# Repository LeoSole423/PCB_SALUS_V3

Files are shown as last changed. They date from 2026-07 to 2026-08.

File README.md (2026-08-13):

# PCB SALUS V3

PCB de control para el robot Ackermann SALUS. Esta revision se inspira en la
arquitectura de `Hoja-Base`, pero usa un ESP32-S3 y se mantiene como un diseno
independiente.

## Abrir el proyecto

En KiCad 10, abre `PCB_SALUS_v3.kicad_pro`. El esquema raiz contiene tres
hojas jerarquicas activas: `ESP32`, `SENSORES` y `ALIMENTACION`.

La PCB esta sincronizada de forma parcial y aun no tiene placement ni ruteo
final. No debe enviarse a fabricar hasta completar la revision electrica,
placement, ruteo, DRC y pruebas de banco.

## Arquitectura actual

- `U8`: ESP32-S3-WROOM-1-N8R2 como controlador de tiempo real e I/O.
- `U9`: buck AP63203WU-7 que convierte `5V_SYS` a `+3.3V`.
- Dos receptaculos USB-C: `J3` para UART0 mediante CP2102N y `J16` para el USB
  nativo del ESP32-S3.
- BMI088, I2C externo, puente BTS7960, salidas de reles, sensores Hall,
  finales de carrera, acelerador, RF PPM, UART1 y dos headers de servo.
- Entrada manual de 5 V por `J5` y entrada manual de 7 V por `J19`.

## Documentacion

- [Contexto del proyecto](docs/00_CONTEXTO_PROYECTO.md)
- [Estructura del esquematico y librerias](docs/01_ESTRUCTURA_ESQUEMATICO_Y_LIBRERIAS.md)
- [Validacion y pruebas](docs/02_VALIDACION_Y_PRUEBAS.md)
- [Revision BOM y huellas JLCPCB](docs/03_REVISION_BOM_JLCPCB.md)
- [Puente H BTS7960](docs/04_PUENTE_H_BTS7960.md)
- [Mapa de submodulos y pinout](docs/05_MAPA_DE_SUBMODULOS_Y_PINOUT.md)
- [Revision V3](docs/06_REVISION_V3_2026-07-15.md)
- [Generacion CPL auditable KiCad → JLCPCB](docs/07_CPL_AUDITABLE_KICAD_JLCPCB.md)
- [Validacion del filtro PWM del acelerador](docs/08_VALIDACION_FILTRO_ACELERADOR_PWM.md)

## CPL para JLCPCB

Para toda exportación futura de montaje usar exclusivamente
`tools/jlc_cpl.py` y el perfil versionado `config/jlcpcb-cpl.json`. La guía
incluye el flujo reproducible para agentes, auditoría de centroides y
calibración desde el visor de JLCPCB. No editar rotaciones o posiciones
directamente en un CSV.

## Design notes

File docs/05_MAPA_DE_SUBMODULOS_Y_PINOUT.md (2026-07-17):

# Mapa de submodulos y pinout

Fecha de actualizacion: 2026-07-15.

## Alimentacion

`J5` recibe `5V_SYS` desde el step-down externo. `U9` AP63203WU-7, `L2`, C28,
C30/C31 y C22/C23 generan `+3.3V` para la logica. `J19` recibe `+7V` externo
para los servos; no atraviesa el buck de 3.3 V.

## ESP32-S3

U8 es `ESP32-S3-WROOM-1-N8R2`. Las etiquetas activas del esquema relacionan
las interfaces de la siguiente forma.

| Funcion | Red | GPIO / pin U8 |
|---|---|---|
| I2C SDA / SCL | I2C_SDA / I2C_SCL | GPIO7 / GPIO8 |
| SPI MOSI / MISO / reloj | SPI_MOSI / SPI_MISO / SPI_CLOCK | GPIO11 / GPIO13 / GPIO12 |
| BMI088 CS accel / gyro | CS_ACCEL / CS_GIRO | GPIO9 / GPIO10 |
| BMI088 INT accel / gyro | DR_ACCEL / DR_GIRO | GPIO14 / GPIO15 |
| BTS7960 R / L PWM | R_PWM / L_PWM | GPIO4 / GPIO5 |
| Habilitacion BTS7960 | HBRIDGE_EN | GPIO6 |
| Finales de carrera | FC_LEFT / FC_RIGHT | GPIO1 / GPIO2 |
| RF PPM | RF_PPM | GPIO16 |
| Rele latch / OE | RELAY_LATCH / RELAY_OE | GPIO38 / GPIO39 |
| Servos | SERVO1_PWM / SERVO2_PWM | GPIO40 / GPIO41 |
| Acelerador PWM | THROTTLE_PWM | GPIO21 |
| UART0 | U0TX / U0RX | TXD0 / RXD0 |
| UART1 | U1_TX / U1_RX | senales expuestas en J4; validar asignacion final en firmware |
| Arranque / reset | BOOT / RESET | GPIO0 / EN |

## USB y programacion

| Interfaz | Conector | Red | Funcion |
|---|---|---|---|
| UART0 USB | J3 | USB_DP / USB_DM | CP2102N U3, UART0 y autoprogramacion Q3/Q4. |
| USB nativo | J16 | USB2_DP / USB2_DM | D- y D+ nativos del ESP32-S3. |
| Debug manual | J1 | U0TX, U0RX, RESET, BOOT | Programacion y diagnostico alternativo. |
| UART1 | J4 | U1_TX, U1_RX, GND | Interfaz externa de tres pines. |

D2 protege J3 y D5 protege J16. Ambos USB-C son SMD para JLCPCB; todos los
demas conectores son headers THT de soldadura manual.

## Sensores

- `U4` BMI088 usa `IMU_3.3`, SPI compartido y CS separados. SDO1 y SDO2 se
  unen a `SPI_MISO`; la seleccion exclusiva depende de `CS_ACCEL` y `CS_GIRO`.
- `J2` conecta AS5600 y `J12/J13` exponen I2C externo: +3.3V, GND, SDA, SCL.
- `J7/J8` son finales de carrera en `FC_LEFT/FC_RIGHT`.
- `J14` recibe `HALL_A`, `HALL_B`, `HALL_C` y GND.
- `J11` corresponde al acelerador y `J15` al receptor RF PPM.

## Actuadores

- `J6` conecta el BTS7960 con GND, +5V, dos EN y `L_PWM/R_PWM`; los pines IS
  siguen sin conectar. Ver [Puente H BTS7960](04_PUENTE_H_BTS7960.md).
- `U5` SN74HC595 y `U6` ULN2003A forman el expansor de salidas para J9/J10.
- `J17` es SERVO2 y `J18` es SERVO1: pin de +7V, GND y PWM segun el orden
  dibujado. Confirmar orden de conector y corriente de servo antes del PCB.

## Pendientes de interfaz

- R2/R3 y el acondicionamiento de finales de carrera requieren valor.
- Nombrar las cargas finales de J9/J10 y la salida de acelerador.
- Definir el modulo GPS RTK, su conector, protocolo y alimentacion.
- Unificar las etiquetas HBRIDGE_EN/HB_EN en la proxima correccion electrica.

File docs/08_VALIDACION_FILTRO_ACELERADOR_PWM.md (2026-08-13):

# Validacion del filtro PWM del acelerador

Fecha de validacion: 2026-08-13.

## Veredicto

Se adopta `R17 = 47 kOhm`, `C20 = 100 nF`, encapsulados 0603 y PWM de
`20 kHz`. La constante de tiempo se conserva en 4.7 ms y no cambian la
huella, el ruteo ni la colocacion.

La cadena real es `GPIO21 / THROTTLE_PWM -> R17 -> C20 a GND -> U7A` (seguidor)
`-> R18 -> J11 / THROTTLE_OUT`, con `R19` como pull-down de salida. `R35 =
100 kOhm` esta directamente en el GPIO: fija nivel bajo durante arranque, pero
no forma un divisor mientras el GPIO conduce activamente.

| Parametro nominal | Resultado |
|---|---:|
| Constante de tiempo R17-C20 | 4.70 ms |
| Corte de -3 dB | 33.86 Hz |
| Respuesta 10-90 % | 10.33 ms |
| Escala de salida R18/R19 | 0.993028 |
| Salida a 100 % PWM, carga alta Z | 3.27699 V |

El LM358 se alimenta con 5 V. La entrada de 0-3.3 V queda dentro de su rango
de modo comun especificado hasta aproximadamente `V+ - 1.5 V`; la carga de
R18/R19 a fondo de escala es solo unos 70 uA. Esta conclusion depende de que
J11 conecte una entrada de alta impedancia, como se asumio para esta revision.

## Simulacion SPICE

Los bancos reproducibles estan en
[`spice/validar_filtro_acelerador.cir`](../spice/validar_filtro_acelerador.cir)
y [`spice/validar_escalon_acelerador.cir`](../spice/validar_escalon_acelerador.cir).
Modelan GPIO de baja impedancia, R35, el RC, un seguidor ideal U7A y la salida
R18/R19. La idealizacion del seguidor es valida para el filtro de 33.86 Hz;
la ganancia-ancho de banda nominal del LM358 es muy superior a esa frecuencia.

Resultados transitorios con ngspice:

| PWM | Ciclo util | Salida media | Rizado pico a pico |
|---:|---:|---:|---:|
| 20 kHz | 0 % | 0 V | 0 V |
| 20 kHz | 10 % | 0.32774 V | 3.18 mV |
| 20 kHz | 50 % | 1.63852 V | 8.77 mV |
| 20 kHz | 90 % | 2.94934 V | 3.22 mV |
| 20 kHz | 100 % | 3.27699 V | 0 V |

El escalon de 0 a 100 % simulado mide 10.327 ms entre 10 y 90 %. Por lo tanto,
el caso de peor rizado nominal a 20 kHz es 8.77 mVpp (0.27 % de 3.3 V): cumple
el limite de 15 mVpp y la respuesta esperada para un mando mecanico.

La comparacion de frecuencia se calculo con la respuesta periodica exacta del
RC, validada por SPICE en 10, 20, 40 y 80 kHz; el maximo ocurre a 50 % de ciclo
util. Se expresa en J11, despues del divisor R18/R19.

| Frecuencia PWM | Rizado maximo a 50 % |
|---:|---:|
| 10 kHz | 17.43 mVpp |
| 20 kHz | 8.72 mVpp |
| 40 kHz | 4.36 mVpp |
| 80 kHz | 2.18 mVpp |
| 100 kHz | 1.74 mVpp |

Subir el PWM disminuye el rizado, pero no resuelve un problema presente. A
cambio, reduce la resolucion de duty util del temporizador LEDC de la
ESP32-S3: con un reloj de 80 MHz, la condicion `frecuencia x 2^bits <= 80 MHz`
permite como maximo 11 bits a 20 kHz, 10 bits a 40 kHz y 9 bits a 80 kHz. Se
mantiene 20 kHz.

## Tolerancias y margen

Para un caso conservador se uso R17 a -1 %, C20 a -10 % y una reduccion
adicional de 15 % de capacidad por sesgo DC: `R = 46.53 kOhm`, `C = 76.5 nF`.
SPICE entrega 11.52 mVpp a 20 kHz y 50 %, aun inferior a 15 mVpp. El tiempo
10-90 % queda aproximadamente entre 7.8 y 11.4 ms en los extremos pasivos;
mas rapido que el nominal no perjudica la respuesta del acelerador.

La corriente de polarizacion del LM358 es tipicamente 20 nA. Incluso usando
250 nA como cota conservadora, R17 puede introducir hasta 11.75 mV de error
DC; es aceptable para una escala de 3.3 V, pero reduce el margen frente a la
solucion original de 4.7 kOhm.
La salida a 100 % se reduce por R18/R19, no por el filtro; una carga externa
de baja impedancia reduciria esa tension y requeriria redisenar la etapa de
salida. No conectar J11 a una carga baja sin revisar ese supuesto.

## Coste y tamano

`R17 = 47 kOhm` y `C20 = 100 nF` conserva exactamente `RC = 4.7 ms`. Ambos
son 0603 y no reducen area de PCB. Se eligieron C25819 para R17 y C14663 para
C20: son piezas Basic de JLCPCB, al igual que C14663 para los otros once
capacitores de 100 nF.

La mayor impedancia aumenta la susceptibilidad a ruido y el error por corriente
de polarizacion indicado arriba. Se acepta para la entrada de alta impedancia
de J11 a cambio de eliminar C1590 y C108463, dos referencias Extended. El
ahorro estimado para cinco PCBA es USD 5.60; confirmar precio y disponibilidad
antes de pagar en [LCSC para C14663](https://www.lcsc.com/product-detail/Multilayer-Ceramic-Capacitors-MLCC-SMD-SMT_YAGEO-CC0603KRX7R9BB104_C14663.html).

## Criterio de banco antes de integrar

1. Con J11 sin carga, medir a 0, 10, 50, 90 y 100 % de PWM con sonda x10 y
   masa corta; esperar los valores medios de la tabla y menos de 15 mVpp.
2. Confirmar que el controlador conectado a J11 acepta 0-3.3 V y presenta alta
   impedancia en toda la escala.
3. Arrancar y resetear la ESP32 verificando que R35 mantiene la salida proxima
   a 0 V hasta que el firmware configure GPIO21.

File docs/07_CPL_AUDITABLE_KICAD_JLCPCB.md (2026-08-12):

# CPL auditable: KiCad → JLCPCB

`tools/jlc_cpl.py` es el único procedimiento admitido para crear un CPL nuevo.
No se editan coordenadas ni rotaciones directamente en un CSV: toda excepción
queda en `config/jlcpcb-cpl.json`, con motivo y fuente.

## Contrato JLCPCB

El archivo final contiene exactamente `Designator,Mid X,Mid Y,Layer,Rotation`.
Las coordenadas llevan `mm`, la capa es `Top` o `Bottom` y la rotación está en
`[0,360)`. JLCPCB interpreta `Mid X/Mid Y` como el centroide de colocación y
la rotación positiva en sentido antihorario. La herramienta parte del origen
auxiliar de KiCad; el perfil especifica el signo de los ejes, por lo que nunca
debe invertirse Y en una hoja de cálculo.

## Centros y reglas

KiCad puede tener tres centros diferentes:

- `anchor`: origen de la huella, que es el origen del exportador de KiCad.
- `pad_center`: centro de la envolvente de pads; útil para hallar anclas
  excéntricas, pero no es automáticamente el centro de montaje.
- `body_center`: estimación a partir de geometría de huella/courtyard.

Si cualquiera difiere más de 0,20 mm, el informe exige una regla explícita o
marca el componente `needs_review`. Esto sucede, por ejemplo, en U1, U8 y
J16. La imagen 3D de JLCPCB no es por sí sola una prueba de que el centro
matemático sea erróneo.

Las reglas tienen precedencia: referencia, LCSC, huella exacta, regex de
familia y base KiCad. Cada una admite `rotation_offset_deg`,
`position_offset_local_mm`, `origin`, `reason`, `source` y `confirmed_on`.
El offset se rota junto con la huella. Dos reglas coincidentes del mismo nivel
son un error: un agente debe resolverlas, no elegir arbitrariamente.

## Flujo para agentes y CI

```bash
/usr/bin/python3 tools/jlc_cpl.py generate PCB_SALUS_v3.kicad_pcb \
  --config config/jlcpcb-cpl.json \
  --bom fabricacion/JLCPCB_2026-08-12_SALUS_v3/PCB_SALUS_v3-JLC-BOM.csv \
  --output /tmp/salus-cpl.csv --raw-output /tmp/salus-cpl-raw.csv \
  --report /tmp/cpl-audit.json --review-output /tmp/cpl-review.csv \
  --overlay /tmp/cpl-overlay.svg

/usr/bin/python3 tools/jlc_cpl.py validate PCB_SALUS_v3.kicad_pcb \
  --config config/jlcpcb-cpl.json --bom fabricacion/JLCPCB_2026-08-12_SALUS_v3/PCB_SALUS_v3-JLC-BOM.csv \
  --cpl /tmp/salus-cpl.csv --report /tmp/cpl-validation.json

/usr/bin/python3 tools/jlc_cpl.py diff /tmp/salus-cpl-raw.csv /tmp/salus-cpl.csv \
  --output /tmp/cpl-diff.json
```

`generate` retorna 0 solo si la lista es completa y ningún elemento exige
revisión; 2 representa un resultado generado pero no liberable; 3 representa
un error de entrada/configuración. Sus informes JSON son la fuente de verdad
para otro agente.

## Calibración desde el visor JLCPCB

Después de cargar Gerbers, BOM y CPL, registrar solo observaciones inequívocas:

```json
{
  "observations": [{
    "reference": "U2",
    "origin": "anchor",
    "rotation_offset_deg": 90,
    "position_offset_local_mm": [0, 0],
    "reason": "Pin 1 del componente JLC coincide con pin 1 de la huella",
    "source": "JLCPCB viewer, captura enlazada",
    "confirmed_on": "2026-08-12"
  }]
}
```

Proponer la modificación sin tocar nada:

```bash
/usr/bin/python3 tools/jlc_cpl.py calibrate config/jlcpcb-cpl.json \
  --observations observaciones.json --output /tmp/reglas-propuestas.json --dry-run
```

Tras revisión humana, ejecutar de nuevo con `--apply`, regenerar, comparar y
volver a inspeccionar. Solo entonces se actualiza el paquete de fabricación y
su checksum. Gerbers y BOM no cambian por una corrección exclusiva del CPL.

La aceptación exige cuerpos sobre pads y pin 1/polaridad correctos para todos
los componentes asimétricos, no solo una previsualización global aparentemente
alineada.

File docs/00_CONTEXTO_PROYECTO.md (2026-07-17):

# Contexto de PCB SALUS V3

## Objetivo

SALUS V3 es la placa de control de bajo nivel para un robot Ackermann. La
Jetson Orin Nano conserva las tareas de alto nivel y el ESP32-S3 se ocupa de
FreeRTOS, adquisicion de sensores, PID, entradas, salidas y comunicaciones de
campo. La placa no controla directamente la potencia de traccion.

## Arquitectura confirmada

```text
Jetson Orin Nano <--> USB / UART segun interfaz <--> ESP32-S3
                                                    |-- sensores e IMU
                                                    |-- actuadores de logica
                                                    `-- headers de servo

Step-down externo 5 V --> J5 --> 5V_SYS --> AP63203WU-7 --> +3.3V
Step-down externo 7 V --> J19 --> +7V --> J17/J18 (servos)
```

- `U8` es `ESP32-S3-WROOM-1-N8R2`, con 8 MB de flash y 2 MB de PSRAM.
- `U9` es `AP63203WU-7`, buck fijo de 3.3 V desde el riel `5V_SYS`.
- `J3` ofrece USB-C a UART0 mediante `U3` CP2102N y conserva la
  autoprogramacion por `Q3/Q4`.
- `J16` ofrece USB-C nativo del ESP32-S3 mediante `USB2_DP` y `USB2_DM`.
- `J17` y `J18` son headers de tres pines para servo; `J19` recibe el riel de
  7 V externo.

## Ensamblaje JLCPCB

La placa requiere PCBA Standard por el modulo ESP32-S3 y la IMU BMI088. Los
componentes SMD se montaran en la cara superior. Todos los headers son THT y
se compran/sueldan manualmente: permanecen en la PCB para fabricar sus agujeros
metalizados, pero se excluyen de la BOM y CPL de ensamblaje.

Las existencias y precios de JLCPCB son una fotografia de la fecha de revision;
deben comprobarse nuevamente antes del pedido.

## Limites actuales

- `J5` recibe 5 V ya regulados. El esquema activo no implementa corte por
  sobretension, fusible ni TVS de entrada frente a una falla aguas arriba.
- `J19` recibe 7 V ya regulados para los servos. La capacidad de corriente del
  header y del cableado debe confirmarse frente a los picos de servo antes del
  layout final.
- La proteccion de la Jetson y sus 19 V no pertenece a esta placa.
- GPS RTK de doble antena sigue sin modulo, conector, protocolo ni pinout
  definido.
- `R2` y `R3` aun tienen valor `R`; no se pueden comprar ni montar hasta que
  se defina el acondicionamiento de los finales de carrera.

## Principios de diseno

- Mantener potencia de traccion, 7 V de servos y logica de 3.3 V separados en
  placement, retorno de masa y ruteo.
- Respetar el keep-out de antena del ESP32-S3 en todas las capas de cobre.
- Situar TVS junto a cada USB-C y desacoples junto a sus pines de alimentacion.
- Resolver ERC, DRC, fiduciales, puntos de prueba y conexion de entradas
  externas antes de fabricar.

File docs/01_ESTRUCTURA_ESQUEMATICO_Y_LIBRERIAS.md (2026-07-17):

# Estructura del esquematico y librerias

## Hojas activas

| Hoja | Responsabilidad |
|---|---|
| `ESP32.kicad_sch` | ESP32-S3, USB-C UART0, USB-C nativo, CP2102N y autoprogramacion. |
| `SENSORES.kicad_sch` | IMU, sensores, BTS7960, reles, servo y conectores de campo. |
| `ALIMENTACION.kicad_sch` | Entrada 5 V, buck AP63203WU-7, entrada 7 V y rieles globales. |

El archivo raiz `PCB_SALUS_v3.kicad_sch` solo organiza las hojas. Las senales
de aplicacion se intercambian por etiquetas globales y los rieles usan simbolos
de potencia. Antes de crear una hoja nueva, definir su alimentacion, interfaz
y conector asociado.

## Bibliotecas del proyecto

`sym-lib-table` y `fp-lib-table` hacen que el proyecto use bibliotecas locales
de `Libs/` ademas de las bibliotecas estandar de KiCad.

```text
PCB_SALUS_v3/
  Libs/
    Symb/Simbolos.kicad_sym
    Footprints/Footprints.pretty/
    3D/
```

Usar una huella local solo cuando la huella estandar no coincida con el dibujo
mecanico del MPN. Para cada pieza SMD, verificar simbolo, pinout, pad 1,
encapsulado, MPN, fabricante y `LCSC PN`. Los headers THT llevan una huella
estandar de KiCad pero se anotan como `Compra manual` y se excluyen de PCBA.

## Actualizar la PCB

Despues de guardar cambios en las hojas, abrir el editor PCB y usar
`Herramientas -> Actualizar PCB desde el esquematico` (F8). Revisar la lista de
cambios antes de aceptar; no mover ni borrar componentes que ya hayan sido
colocados sin revisar el impacto. Esta accion no reemplaza el DRC.

## Modelos 3D

Los modelos de `Libs/3D/` son utiles para comprobar interferencias mecanicas,
pero no validan pinout, pad mapping ni compatibilidad con JLCPCB.

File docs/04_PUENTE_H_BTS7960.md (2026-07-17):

# Puente H BTS7960 para direccion

## Alcance

`J6` conecta la PCB SALUS V2 con un modulo externo IBT-2 basado en dos
BTS7960. El modulo conmuta la potencia del motor delantero; la PCB solo entrega
logica de 5 V y senales de control. La corriente del motor no debe circular por
la PCB SALUS ni por este conector de senales.

## Conexion actual de J6

| Pin J6 | Red SALUS | Funcion esperada del modulo |
|---|---|---|
| 1 | GND | Masa de logica. |
| 2 | +5V | Alimentacion de la logica del modulo. |
| 3 | Sin etiqueta | R_IS, sensado de corriente de un sentido. |
| 4 | Sin etiqueta | L_IS, sensado de corriente del otro sentido. |
| 5 | HBRIDGE_EN | R_EN. |
| 6 | HBRIDGE_EN | L_EN. |
| 7 | L_PWM | Entrada PWM de un sentido. |
| 8 | R_PWM | Entrada PWM del sentido opuesto. |

La conexion de los dos `EN` a `HBRIDGE_EN` es valida: en bajo deshabilita el
puente y en alto permite operar ambos sentidos. El firmware debe garantizar que
solo uno entre `L_PWM` y `R_PWM` este activo a la vez. Ambos en bajo dejan el
motor sin mando; para un paro seguro, poner `HBRIDGE_EN` en bajo.

Los modulos IBT-2 no tienen una numeracion fisica universal. Antes de conectar
la primera vez, comparar la serigrafia del modulo real y el pin 1 del cable con
esta tabla. No usar solo fotos de vendedores como referencia de pinout.

## Recomendaciones de hardware

1. Agregar un pull-down externo de 10 kOhm desde `HBRIDGE_EN` a GND. Deja el
   puente deshabilitado mientras el ESP32 arranca, se resetea o queda sin
   alimentacion.
2. Agregar pull-downs de 10 kOhm desde `L_PWM` y `R_PWM` a GND. Evitan pulsos
   de mando durante el arranque. No usar pull-ups a 5 V en estas redes: pueden
   retroalimentar un ESP32 apagado.
3. Si el cable entre PCB y modulo no es muy corto, agregar resistores serie de
   100 a 330 Ohm en `HBRIDGE_EN`, `L_PWM` y `R_PWM`, ubicados en la PCB SALUS.
   Reducen ringing, EMI y corriente de ESD hacia el ESP32.
4. Considerar un TVS de baja capacitancia para las tres senales y GND si el
   cable sale de una caja protegida o supera aproximadamente 20 cm. No es
   obligatorio para un cable interno corto, pero mejora robustez en un robot.
5. El modulo debe tener cerca de sus bornes `B+` y `B-` un capacitor ceramico de
   100 nF y un electrolitico low-ESR de al menos 470 uF, ambos con tension
   nominal superior al riel del motor. La foto muestra un electrolitico en el
   modulo; comprobar valor, tension y distancia real a los bornes. Estos
   capacitores no reemplazan la proteccion ni el filtrado del riel de motor.
6. Unir GND de logica y el negativo de potencia del modulo en el sistema, pero
   llevar el retorno de corriente de motor directamente a la distribucion de
   potencia. No usar la masa de J6 ni la PCB SALUS como retorno de motor.

El BTS7960 admite entradas logicas compatibles con 3.3 V en aplicaciones
tipicas. Aun asi, se debe probar con el modulo real y limitar la prueba inicial
con fuente de laboratorio: los modulos clon pueden variar en sus redes de
entrada.

## Uso de R_IS y L_IS

Cada BTS7960 tiene un pin `IS`: es una fuente de corriente proporcional a la
corriente del lado alto activo y tambien comunica fallas. No es una salida
digital. En el IC original, la relacion nominal es `I_motor / I_IS = 8500`; un
resistor externo de 1 kOhm a GND produciria aproximadamente
`V_IS = I_motor / 8.5 A` en operacion normal. Durante una falla, la salida
indica el estado mediante una corriente limitada.

En modulos IBT-2 el resistor de conversion puede estar ya instalado y su valor
no es consistente entre clones. Por eso, antes de llevar `IS` a un ADC:

1. Con el modulo apagado, medir resistencia entre cada `R_IS`/`L_IS` y GND.
2. Con fuente limitada y motor sin carga, medir la tension `IS` para una
   corriente conocida.
3. Confirmar que la tension maxima, incluidos transitorios, nunca supera 3.3 V.
4. Solo entonces conectar a un ADC1 del ESP32, preferentemente GPIO36
   (`SENSOR_VP`) y GPIO39 (`SENSOR_VN`), que no compiten con Wi-Fi.

Si se usan los dos canales, proponer en la proxima iteracion: etiqueta
`HBRIDGE_R_IS` y `HBRIDGE_L_IS`, resistor serie de 4.7 kOhm a 10 kOhm hacia el
ADC, capacitor de 10 nF a GND en el lado del ADC y clamp a 3.3 V validado para
la corriente de falla. No conectar `IS` directamente al ESP32 hasta medir el
modulo real, porque un nivel de 5 V puede danar su ADC.

La medicion solo representa el semicircuito que esta conduciendo. Debe leerse
el canal asociado al sentido ordenado y calibrarse en software; no sustituye un
sensor de corriente de precision ni una proteccion primaria de sobrecorriente.

## Estado de revision

- `J6` usa `PinHeader_2x04_P2.54mm_Vertical`. Es un header THT vertical de
  montaje manual: JLCPCB debe fabricar los agujeros y pads, pero no montarlo.
  Debe excluirse de la BOM y CPL de ensamblaje JLCPCB.
- Los pines 3 y 4 quedaron como redes sin etiqueta. Si no se usaran ahora,
  colocar marcadores `No connect`; si se reservaran, etiquetarlos como
  `HBRIDGE_R_IS` y `HBRIDGE_L_IS`.
- La relacion completa con la ESP32 y el resto de los conectores esta en el
  [mapa de submodulos y pinout](05_MAPA_DE_SUBMODULOS_Y_PINOUT.md).

## Fuente tecnica

- [Datasheet oficial BTS7960 de Infineon](https://www.infineon.com/assets/row/public/documents/10/57/infineon-bts7960-ds-en.pdf): funcion de `IS`, relacion nominal de corriente y diagnostico.

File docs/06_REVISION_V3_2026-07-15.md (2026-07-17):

# Revision V3 - 2026-07-15

## Cambios aplicados

- Se incorporo `ALIMENTACION.kicad_sch` a la jerarquia raiz.
- U8 quedo fijado como `ESP32-S3-WROOM-1-N8R2` / `C2913204`.
- U9 quedo fijado como `AP63203WU-7` / `C780769`; L2 usa
  `FXL0530-4R7-M` / `C177246` y su huella dedicada de KiCad.
- C28 recibio huella y pieza de 10 uF. C30/C31 pasaron a una pieza real de
  22 uF (`C45783`) en lugar del MPN previo de 10 uF.
- Se completaron huellas 0603 y MPN/LCSC de los pasivos con valor definido.
- J19 recibio huella THT 1x02; los headers se anotaron como compra manual.

## Hallazgos sin corregir electricamente

| Prioridad | Hallazgo | Accion futura |
|---|---|---|
| Alta | No hay proteccion ante sobrevoltaje, polaridad inversa ni corto en J5. | Definir responsabilidad entre step-down externo y placa. |
| Alta | J19/J17/J18 usan header 2.54 mm para 7 V de servo; falta validar corriente, cable y ancho de pista. | Seleccionar interconexion acorde al pico real y rutear potencia. |
| Alta | PCB sin Edge.Cuts, con 210 conexiones sin rutear, 29 componentes del esquema ausentes y 8 obsoletos. | Ejecutar F8 en PCB Editor, dibujar contorno y realizar placement/ruteo. |
| Alta | DRC actual: 137 violaciones; predominan contorno inexistente, drills de 0.20 mm fuera de la regla actual y serigrafia sobre pads. | Configurar reglas de fabricacion y repetir DRC despues de layout. |
| Media | R2/R3 no tienen valor electrico. | Definir filtro/pull-up de finales de carrera y seleccionar pieza. |
| Media | ERC: HBRIDGE_EN y HB_EN comparten red. | Unificar nombre cuando se haga la revision funcional. |
| Media | SW1/SW2 generan cuatro avisos ERC por sus tipos de pin; la cobertura ESD USB aun requiere revision de layout. | Corregir tipos de simbolo y revisar USB antes de fabricar. |
| Media | BMI088 INT2 no se usa; MISO compartido esta excluido de ERC intencionalmente. | Confirmar configuracion y firmware durante pruebas. |

## Verificacion de huellas

- ESP32-S3: simbolo y huella `RF_Module:ESP32-S3-WROOM-1` corresponden a la
  variante WROOM-1 con antena integrada; el keep-out se valida en layout.
- AP63203WU-7: huella TSOT-23-6 y pinout del simbolo KiCad se revisaron contra
  la documentacion de Diodes Incorporated.
- L2: la huella `L_Changjiang_FXL0530` corresponde al MPN seleccionado.
- CP2102N, BMI088, USB-C, SP0503BAHTG, SS8050 y los SOIC existentes conservan
  huellas compatibles con sus encapsulados registrados. La confirmacion final
  de pad 1 y rotacion se hara durante placement/CPL.

## Cobertura de revision

Se exportaron BOM y netlist desde la raiz y se ejecuto ERC. KiCad CLI no ofrece
una accion para actualizar PCB desde el esquematico y los binarios graficos de
esta instalacion no inician por una incompatibilidad de `libpthread` del snap;
la sincronizacion debe hacerse desde PCB Editor con F8. No se realizaron cambios
de topologia, valores, simulaciones SPICE, placement ni ruteo.

## Datasheets locales

Se creo `datasheets/` con PDFs de AP63203WU-7, ESP32-S3-WROOM-1-N8R2, BMI088,
CP2102N, SP0503BAHTG, SS14, SS8050, SN74HC595DR, ULN2003BDR, LM358DR y SW1/SW2.
El sincronizador no encontro PDF para pasivos, headers manuales, ferrita, L2 y
el USB-C; esto es una brecha documental, no una sustitucion de las propiedades
MPN/LCSC ya asignadas.

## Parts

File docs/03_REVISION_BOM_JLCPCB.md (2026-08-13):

# Revision de BOM y huellas para JLCPCB

Fecha de revision: 2026-07-15.

## Alcance

Se revisaron `ESP32.kicad_sch`, `SENSORES.kicad_sch` y
`ALIMENTACION.kicad_sch`. Todos los SMD con valor definido tienen huella, MPN,
fabricante y `LCSC PN`. La excepcion es `R2/R3`: su valor sigue siendo `R`, por
lo cual quedan sin pieza de compra y no se deben montar.

Los stocks son una fotografia del 2026-07-15. Confirmar disponibilidad, precio,
Basic/Extended y elegibilidad Standard PCBA al preparar el pedido final.

El pedido debe configurarse como `Standard PCBA`, cara superior. U4 (BMI088)
y U8 (ESP32-S3-WROOM-1-N8R2) requieren esta modalidad de ensamblaje; Economic
PCBA no es una opcion valida para esta placa.

## Piezas criticas

| Referencias | MPN / LCSC PN | Huella | Categoria JLC | Stock observado | Decision |
|---|---|---|---|---:|---|
| U8 | ESP32-S3-WROOM-1-N8R2 / C2913204 | RF_Module:ESP32-S3-WROOM-1 | Extended, Standard | 17,776 | Keep-out de antena obligatorio. |
| U9 | AP63203WU-7 / C780769 | TSOT-23-6 | Extended | 615 | Buck fijo de 3.3 V. |
| L2 | FXL0530-4R7-M / C177246 | L_Changjiang_FXL0530 | Extended | 150,986 | 4.7 uH, 4.5 A nominal, 5 A Isat. |
| C28 | CL21A106KPFNNNE / C17024 | 0805 | Extended | 1,868,129 | 10 uF para entrada del buck. |
| C30,C31 | CL21A226MAQNNNE / C45783 | 0805 | Extended | 5,389,915 | 22 uF; reemplaza MPN erroneo de 10 uF. |
| U3 | CP2102N-A02-GQFN24R / C969151 | QFN-24-EP 4x4 | Extended | 5,744 | USB-UART y pad expuesto a GND. |
| U4 | BMI088 / C194919 | Bosch LGA-16 4.5x3 | Extended, Standard | 2,378 | Verificar orientacion, desacople y placement. |
| J3,J16 | GT-USB-7010ASV / C2988369 | USB-C G-Switch | Extended | 32,723 | Un conector UART0 y uno USB nativo. |
| D2,D5 | SP0503BAHTG / C3040626 | SOT-143 | Extended | 28,729 | TVS USB, colocar junto al conector correspondiente. |

## Pasivos consolidados

| Valor | MPN / LCSC PN | Huella | Referencias de esta revision |
|---|---|---|---|
| 100 nF | CC0603KRX7R9BB104 / C14663 | 0603 | C6,C7,C12,C13,C15,C17-C23 |
| 10 uF | CL21A106KPFNNNE / C17024 | 0805 | C5,C8,C28 |
| 22 uF | CL21A226MAQNNNE / C45783 | 0805 | C30,C31 |
| 22 ohm | 0603WAF220JT5E / C23345 | 0603 | R27,R28 |
| 330 ohm | 0603WAF3300T5E / C23138 | 0603 | R11,R18,R20 |
| 4.7 kohm | 0603WAF4701T5E / C23162 | 0603 | R21 |
| 10 kohm | 0603WAF1002T5E / C25804 | 0603 | R1,R8,R9,R12-R16,R22-R24,R34,R36 |
| 47 kohm | 0603WAF4702T5E / C25819 | 0603 | R17,R19 |
| 100 kohm | 0603WAF1003T5E / C25803 | 0603 | R35 |

Los restantes SMD ya conservaban MPN/LCSC validos en el esquema. `R2` y `R3`
mantienen huella 0603 pero no se incluyen como linea de compra hasta definir su
valor electrico.

## Conectores THT manuales

| Referencias | Huella | Uso |
|---|---|---|
| J1,J9,J10 | Header vertical 1x06 P2.54 mm | Debug y cargas. |
| J2,J12,J13,J14 | Header vertical 1x04 P2.54 mm | I2C y sensores. |
| J4,J15,J17,J18 | Header vertical 1x03 P2.54 mm | UART, RF y servos. |
| J5,J7,J8,J11,J19 | Header vertical 1x02 P2.54 mm | Entradas, sensores y 7 V. |
| J6 | Header vertical 2x04 P2.54 mm | BTS7960. |

Todos estan anotados como `Compra manual`; excluirlos de BOM y CPL de JLCPCB.

## Verificacion mecanica pendiente

- Mantener el keep-out de antena de U8 libre de cobre, vias, pistas y metal.
- Colocar D2/D5 antes de las pistas USB y adyacentes a J3/J16.
- Colocar C28, C30/C31 y L2 segun el loop corto VIN-SW-L-COUT de U9.
- Revisar la corriente admisible de J19, J17, J18 y sus pistas antes de usar
  servos con picos cercanos a 5 A.

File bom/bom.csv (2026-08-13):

Reference | Qty | Value | Footprint | MPN | Manufacturer | LCSC | LC_Stock | Chosen_Distributor | Datasheet | Validated | DNP | Notes
C6,C7,C12,C13,C19,C18,C21,C15,C20,C17,C22,C23 | 12 | 100nF | 0603 | CC0603KRX7R9BB104 | Yageo | C14663 |  |  |  |  |  | Huella asignada; consolidar propiedades al cerrar BOM.
C8,C5,C28 | 3 | 10uF | 0805 | CL21A106KPFNNNE | Samsung Electro-Mechanics | C17024
C16,C14 | 2 | 4.7uF | 0805 | CC0805KKX5R6BB475 | YAGEO | C107125
C30 | 1 | 22uF | CP_EIA-3528-21_Kemet-B | T491B226K010AT | KEMET | C117030 |  |  | https://content.kemet.com/datasheets/KEM_T2005_T491.pdf
D1 | 1 | SM712-02HTG | SOT-23 | SM712-02HTG | DOWO | C5449363 |  |  | https://www.littelfuse.com/~/media/electronics/datasheets/tvs_diode_arrays/littelfuse_tvs_diode_array_sm712_datasheet.pdf.pdf
D5 | 1 | SP0503BAHTG | SOT-143 | SP0503BAHTG | Littelfuse | C3040626 |  |  | http://www.littelfuse.com/~/media/files/littelfuse/technical%20resources/documents/data%20sheets/sp05xxba.pdf
D9,D7 | 2 | SS14 | SMA | SS14 | Yangzhou Yangjie Electronic Technology | C2480 |  |  | https://www.vishay.com/docs/88746/ss12.pdf
FB1 | 1 | 600R@100MHz | 0603 | GZ1608D601TF | Sunlord | C1002
J16 | 1 | USB_NATIVO | USB_C_Receptacle_G-Switch_GT-USB-7010ASV | GT-USB-7010ASV | G-Switch | C2988369 |  |  | https://www.usb.org/sites/default/files/documents/usb_type-c.zip
R17,R19 | 2 | 47k | 0603 | 0603WAF4702T5E | UNI-ROYAL | C25819
R20,R11,R18 | 3 | 330 | 0603 | 0603WAF3300T5E | Walsin Technology | C23138 |  |  |  |  |  | Huella asignada.
R21,R2,R3 | 3 | 4.7k | 0603 | 0603WAF4701T5E | Walsin Technology | C23162 |  |  |  |  |  | Huella asignada.
R23,R22,R37,R24,R13,R1,R14,R16,R36,R12,R15,R34 | 12 | 10k | 0603 | 0603WAF1002T5E | UNI-ROYAL(Uniroyal Elec) | C25804 |  |  |  |  |  | Huella asignada.
R25,R26 | 2 | 5.1k | 0603 | 0603WAF5101T5E | UNI-ROYAL(Uniroyal Elec) | C23186
R28,R27 | 2 | 22 | 0603 | 0603WAF220JT5E | Walsin Technology | C23345
R33,R30,R32,R31,R29 | 5 | 1k | 0603 | 0603WAF1001T5E | UNI-ROYAL(Uniroyal Elec) | C21190 |  |  |  |  |  | Huella asignada.
R35 | 1 | 100k | 0603 | 0603WAF1003T5E | Walsin Technology | C25803
SW1,SW2 | 2 |  | Switch-Definitivo | TS-1187A-B-A-B | XKB Connection | C318884 |  |  | http://www.helloxkb.com/uploads/qingchukaiguan/TS-1187A-X-X-X.pdf
U1 | 1 | AMS1117CD-3.3 | TO-252-3_TabPin2 | AMS1117CD-3.3 | Advanced Monolithic Systems | C841796 |  |  | http://www.advanced-monolithic.com/pdf/ds1117.pdf
U2 | 1 | SP3485EN | SOIC-8_3.9x4.9mm_P1.27mm | SP3485EN-L/TR | MaxLinear | C8963 |  |  | http://www.icbase.com/pdf/SPX/SPX00480106.pdf
U4 | 1 | BMI088 | Bosch_LGA-16_4.5x3mm_P0.5mm_LayoutBorder7x1y_ClockwisePinNumbering | BMI088 | Bosch Sensortec | C194919 |  |  | https://www.bosch-sensortec.com/media/boschsensortec/downloads/datasheets/bst-bmi088-ds001.pdf
U5 | 1 | 74HC595 | SOIC-16_3.9x9.9mm_P1.27mm | SN74HC595DR | Texas Instruments | C10092 |  |  | http://www.ti.com/lit/ds/symlink/sn74hc595.pdf |  |  | Montaje SMD JLCPCB.
U6 | 1 | ULN2003A | SOIC-16_3.9x9.9mm_P1.27mm | ULN2003BDR | Texas Instruments | C157485 |  |  | http://www.ti.com/lit/ds/symlink/uln2003a.pdf |  |  | Montaje SMD JLCPCB.
U7 | 1 | LM358 | SOIC-8_3.9x4.9mm_P1.27mm | LM358DR | Texas Instruments | C5423 |  |  | http://www.ti.com/lit/ds/symlink/lm2904-n.pdf |  |  | Montaje SMD JLCPCB.
U8 | 1 | ESP32-S3-WROOM-1 | ESP32-S3-WROOM-1 | ESP32-S3-WROOM-1-N8R2 | Espressif Systems | C2913204 |  |  | https://www.espressif.com/sites/default/files/documentation/esp32-s3-wroom-1_wroom-1u_datasheet_en.pdf |  |  | Modulo Wi-Fi/BLE SMD; mantener libre de cobre y componentes el keep-out de antena indicado por Espressif. JLCPCB: Extended, Standard PCBA.

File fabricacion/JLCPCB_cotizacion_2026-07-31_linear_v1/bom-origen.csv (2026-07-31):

Reference | Value | Footprint | LCSC | MPN | Manufacturer | DNP
C5,C8,C28 | 10uF | Capacitor_SMD:C_0805_2012Metric | C17024 | CL21A106KPFNNNE | Samsung Electro-Mechanics
C6,C12,C13,C15,C17-C19,C21-C23 | 100nF | Capacitor_SMD:C_0603_1608Metric | C1590 | CL10B104KA8NNNC | Samsung Electro-Mechanics
C14,C16 | 4.7uF | Capacitor_SMD:C_0805_2012Metric | C107125 | CC0805KKX5R6BB475 | YAGEO
C20 | 1uF | Capacitor_SMD:C_0603_1608Metric | C108463 | 0603B105K160CT | Walsin Technology
C30 | 22uF | Capacitor_Tantalum_SMD:CP_EIA-3528-21_Kemet-B | C117030 | T491B226K010AT | KEMET
D5 | SP0503BAHTG | Package_TO_SOT_SMD:SOT-143 | C3040626 | SP0503BAHTG | Littelfuse
D7,D9 | SS14 | Diode_SMD:D_SMA | C2480 | SS14 | Yangzhou Yangjie Electronic Technology
FB1 | 600R@100MHz | Inductor_SMD:L_0603_1608Metric_Pad1.05x0.95mm_HandSolder | C1002 | GZ1608D601TF | Sunlord
J1 | Debug_U0 | Connector_PinHeader_2.54mm:PinHeader_1x06_P2.54mm_Vertical |  | Header generico THT 1x06 P2.54 mm | Compra manual
J2 | S_GIRO | Connector_PinHeader_2.54mm:PinHeader_1x04_P2.54mm_Vertical |  | Header manual THT 1x04 P2.54 mm | Compra manual
J4 | Uart1 | Connector_PinHeader_2.54mm:PinHeader_1x03_P2.54mm_Vertical |  | Header generico THT 1x03 P2.54 mm | Compra manual
J5 | 5V_IN | Connector_PinHeader_2.54mm:PinHeader_1x02_P2.54mm_Vertical |  | Header manual THT 1x02 P2.54 mm | Compra manual
J6 | IBT_2 | Connector_PinHeader_2.54mm:PinHeader_2x04_P2.54mm_Vertical |  | Header manual THT 2x04 P2.54 mm | Compra manual
J7 | FC1 | Connector_PinHeader_2.54mm:PinHeader_1x02_P2.54mm_Vertical |  | Header manual THT 1x02 P2.54 mm | Compra manual
J8 | FC2 | Connector_PinHeader_2.54mm:PinHeader_1x02_P2.54mm_Vertical |  | Header manual THT 1x02 P2.54 mm | Compra manual
J9 | RELES_1 | Connector_PinHeader_2.54mm:PinHeader_1x06_P2.54mm_Vertical |  | Header manual THT 1x06 P2.54 mm | Compra manual
J10 | RELES_2 | Connector_PinHeader_2.54mm:PinHeader_1x06_P2.54mm_Vertical |  | Header manual THT 1x06 P2.54 mm | Compra manual
J11 | Throttle | Connector_PinHeader_2.54mm:PinHeader_1x02_P2.54mm_Vertical |  | Header manual THT 1x02 P2.54 mm | Compra manual
J12 | I2C_EXT1 | Connector_PinHeader_2.54mm:PinHeader_1x04_P2.54mm_Vertical |  | Header manual THT 1x04 P2.54 mm | Compra manual
J13 | I2C_EXT2 | Connector_PinHeader_2.54mm:PinHeader_1x04_P2.54mm_Vertical |  | Header manual THT 1x04 P2.54 mm | Compra manual
J14 | S_HALL | Connector_PinHeader_2.54mm:PinHeader_1x04_P2.54mm_Vertical |  | Header manual THT 1x04 P2.54 mm | Compra manual
J15 | RF_PPM | Connector_PinHeader_2.54mm:PinHeader_1x03_P2.54mm_Vertical |  | Header manual THT 1x03 P2.54 mm | Compra manual
J16 | USB_NATIVO | Connector_USB:USB_C_Receptacle_G-Switch_GT-USB-7010ASV | C2988369 | GT-USB-7010ASV | G-Switch
J17 | SERVO2 | Connector_PinHeader_2.54mm:PinHeader_1x03_P2.54mm_Vertical |  | Header manual THT 1x03 P2.54 mm | Compra manual
J18 | SERVO1 | Connector_PinHeader_2.54mm:PinHeader_1x03_P2.54mm_Vertical |  | Header manual THT 1x03 P2.54 mm | Compra manual
J19 | +7V_IN | Connector_PinHeader_2.54mm:PinHeader_1x02_P2.54mm_Vertical |  | Header manual THT 1x02 P2.54 mm | Compra manual
J20 | 3V_IN | Connector_PinHeader_2.54mm:PinHeader_1x02_P2.54mm_Vertical
R1,R12,R15,R16,R24,R34,R36 | 10k | Resistor_SMD:R_0603_1608Metric | C25804 | 0603WAF1002T5E | Walsin Technology
R2,R3,R17,R21 | 4.7k | Resistor_SMD:R_0603_1608Metric | C23162 | 0603WAF4701T5E | Walsin Technology
R11,R18,R20 | 330 | Resistor_SMD:R_0603_1608Metric | C23138 | 0603WAF3300T5E | Walsin Technology
R13,R14,R22,R23 | 10k | Resistor_SMD:R_0603_1608Metric | C25804 | 0603WAF1002T5E | UNI-ROYAL(Uniroyal Elec)
R19 | 47k | Resistor_SMD:R_0603_1608Metric | C25819 | 0603WAF4702T5E | Walsin Technology
R25,R26 | 5.1k | Resistor_SMD:R_0603_1608Metric | C23186 | 0603WAF5101T5E | UNI-ROYAL(Uniroyal Elec)
R27,R28 | 22 | Resistor_SMD:R_0603_1608Metric | C23345 | 0603WAF220JT5E | Walsin Technology
R29-R33 | 1k | Resistor_SMD:R_0603_1608Metric | C21190 | 0603WAF1001T5E | UNI-ROYAL(Uniroyal Elec)
R35 | 100k | Resistor_SMD:R_0603_1608Metric | C25803 | 0603WAF1003T5E | Walsin Technology
SW1,SW2 |  | Footprints:Switch-Definitivo | C318884 | TS-1187A-B-A-B | XKB Connection
U1 | AMS1117CD-3.3 | Package_TO_SOT_SMD:TO-252-3_TabPin2 | C841796 | AMS1117CD-3.3 | Advanced Monolithic Systems
U4 | BMI088 | Package_LGA:Bosch_LGA-16_4.5x3mm_P0.5mm_LayoutBorder7x1y_ClockwisePinNumbering | C194919 | BMI088 | Bosch Sensortec
U5 | 74HC595 | Package_SO:SOIC-16_3.9x9.9mm_P1.27mm | C10092 | SN74HC595DR | Texas Instruments
U6 | ULN2003A | Package_SO:SOIC-16_3.9x9.9mm_P1.27mm | C157485 | ULN2003BDR | Texas Instruments
U7 | LM358 | Package_SO:SOIC-8_3.9x4.9mm_P1.27mm | C5423 | LM358DR | Texas Instruments
U8 | ESP32-S3-WROOM-1 | RF_Module:ESP32-S3-WROOM-1 | C2913204 | ESP32-S3-WROOM-1-N8R2 | Espressif Systems

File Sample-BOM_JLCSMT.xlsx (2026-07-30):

Comment | Designator | Footprint | JLCPCB Part #（optional）
100uF | C1 | CAP-SMD_L3.5-W2.8 | C16133
15K | R5,R6 | R0603 | C22809
DC-005-20A_C136744 | DC1 | DC-IN-TH_DC-005-20A | C136744
Header-Female-2.54_1x8 | P2,P3 | HDR-TH_8P-P2.54-V | C27438
K2-1102DP-C4SW-04 | SW1 | KEY-TH_4P-L6.0-W6.0-P4.50-LS6.5 | C110153
ATMEGA328P-PU | U1 | DIP-28_L34.6-W7.3-P2.54-LS10.2-BL | C33901
670688000 | USB1 | USB-B-TH_67068-8000 | C114097

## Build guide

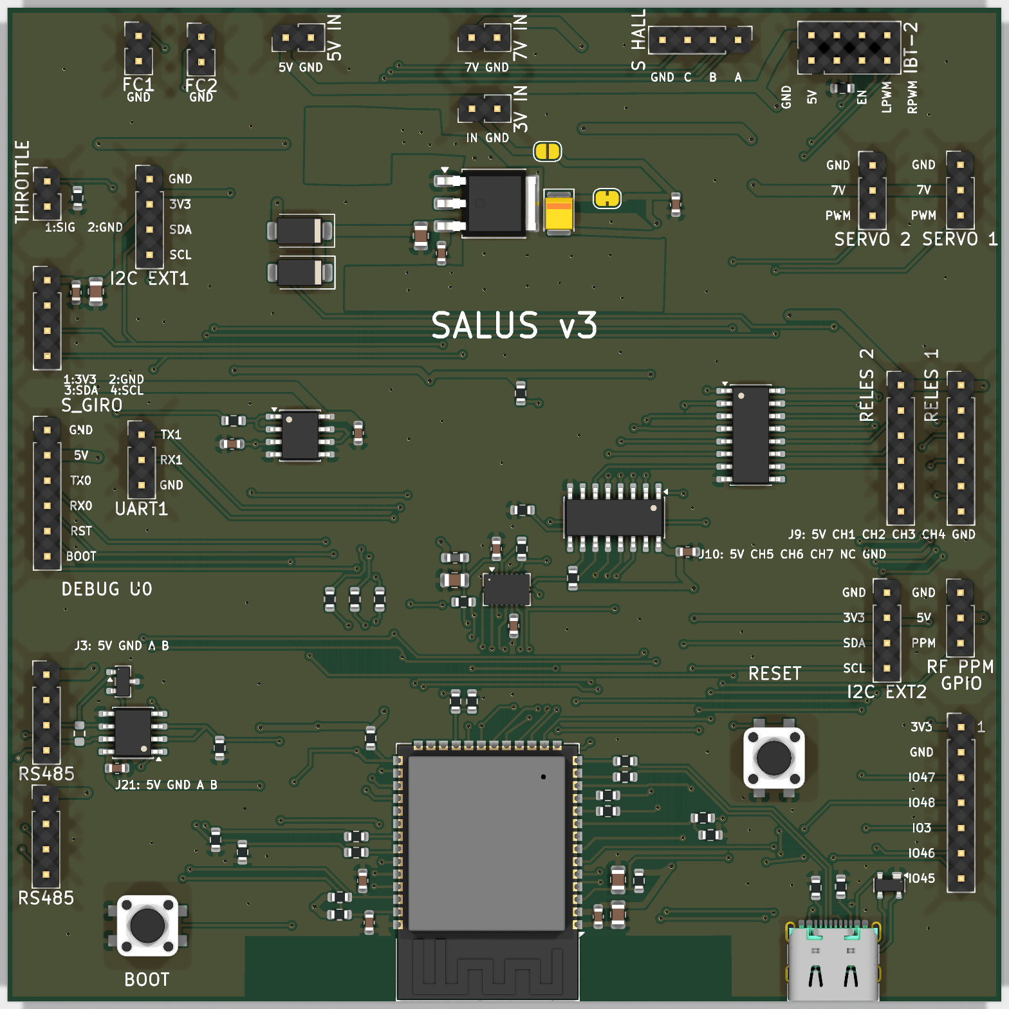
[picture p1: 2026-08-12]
fabricacion/JLCPCB_2026-08-12_SALUS_v3/validacion/render-superior.png

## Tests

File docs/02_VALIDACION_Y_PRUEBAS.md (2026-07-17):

# Validacion y pruebas

## Estado de V3

La V3 cambio el ESP32 clasico y el LDO TLV757 por ESP32-S3 y buck AP63203WU-7.
Por ello, los resultados SPICE historicos de V2 sobre TLV757, OR por diodos y
ESP32-WROOM-32E no son evidencia de funcionamiento de V3 y no deben usarse
para aprobar esta revision.

| Bloque | Estado | Evidencia disponible | Pendiente |
|---|---|---|---|
| Jerarquia KiCad | Revisado | El esquema raiz exporta BOM y netlist con tres hojas. | ERC/DRC final tras ruteo. |
| Buck 5 V a 3.3 V | Revisado en esquema | U9 AP63203WU-7, L2 4.7 uH, C28 10 uF, C30/C31 22 uF y C22/C23 100 nF estan presentes. | Validar layout, arranque, ripple, temperatura y carga real. |
| USB-C UART0 | Revisado en esquema | J3, D2, CP2102N y Q3/Q4 estan presentes. | Enumeracion, carga de firmware y autoprogramacion en banco. |
| USB-C nativo | Revisado en esquema | J16, D5, USB2_DP y USB2_DM estan presentes. | Enumeracion USB nativa y compatibilidad de firmware. |
| ESP32-S3 | Revisado en BOM | U8 fijado como N8R2. | RF, antena, arranque, consumo y perifericos en placa. |
| IMU BMI088 | Revisado en esquema | Alimentacion IMU_3.3, SPI y CS separados. | Comunicacion, calibracion y vibracion en robot. |
| Servos | Pendiente | J17/J18 y J19 estan dibujados. | Corriente, caida de tension, conector/cable y ruido de retorno. |

## ERC registrado

La corrida del 2026-07-15 produjo seis advertencias y ningun error no excluido.

| Hoja | Aviso | Tratamiento en esta etapa |
|---|---|---|
| `ESP32` | Cuatro avisos de tipo de pin de SW1/SW2 frente a pines pasivos o de potencia. | Documentados; corresponden a la definicion de los simbolos de boton y no se cambia el circuito en esta etapa. |
| `SENSORES` | `HBRIDGE_EN` y `HB_EN` nombran la misma red. | Documentado; unificar etiqueta en una futura correccion electrica. |
| `SENSORES` | Conflicto de salida compartida en `SPI_MISO` de BMI088. | Excluido intencionalmente: SDO1/SDO2 comparten MISO y los CS separados seleccionan un sensor por vez. |

## Plan de prueba fisica

1. Alimentar `J5` con 5 V y limite inicial de corriente bajo.
2. Medir `5V_SYS`, `+3.3V` y la temperatura de U9/L2 sin cargas externas.
3. Aplicar carga escalonada al buck y medir ripple de 3.3 V con osciloscopio.
4. Probar por separado J3/CP2102N y J16/USB nativo con PC.
5. Verificar BOOT, RESET y autoprogramacion por UART0.
6. Conectar IMU, I2C y sensores de uno en uno.
7. Conectar los servos con fuente de 7 V limitada; medir picos y caida de
   tension antes de probarlos en el robot.

## Criterio de actualizacion

Cada resultado debe registrar fecha, configuracion, instrumento, limite de
corriente, mediciones y conclusion. Un bloque no se considera probado en robot
sin haber superado primero la prueba de banco.

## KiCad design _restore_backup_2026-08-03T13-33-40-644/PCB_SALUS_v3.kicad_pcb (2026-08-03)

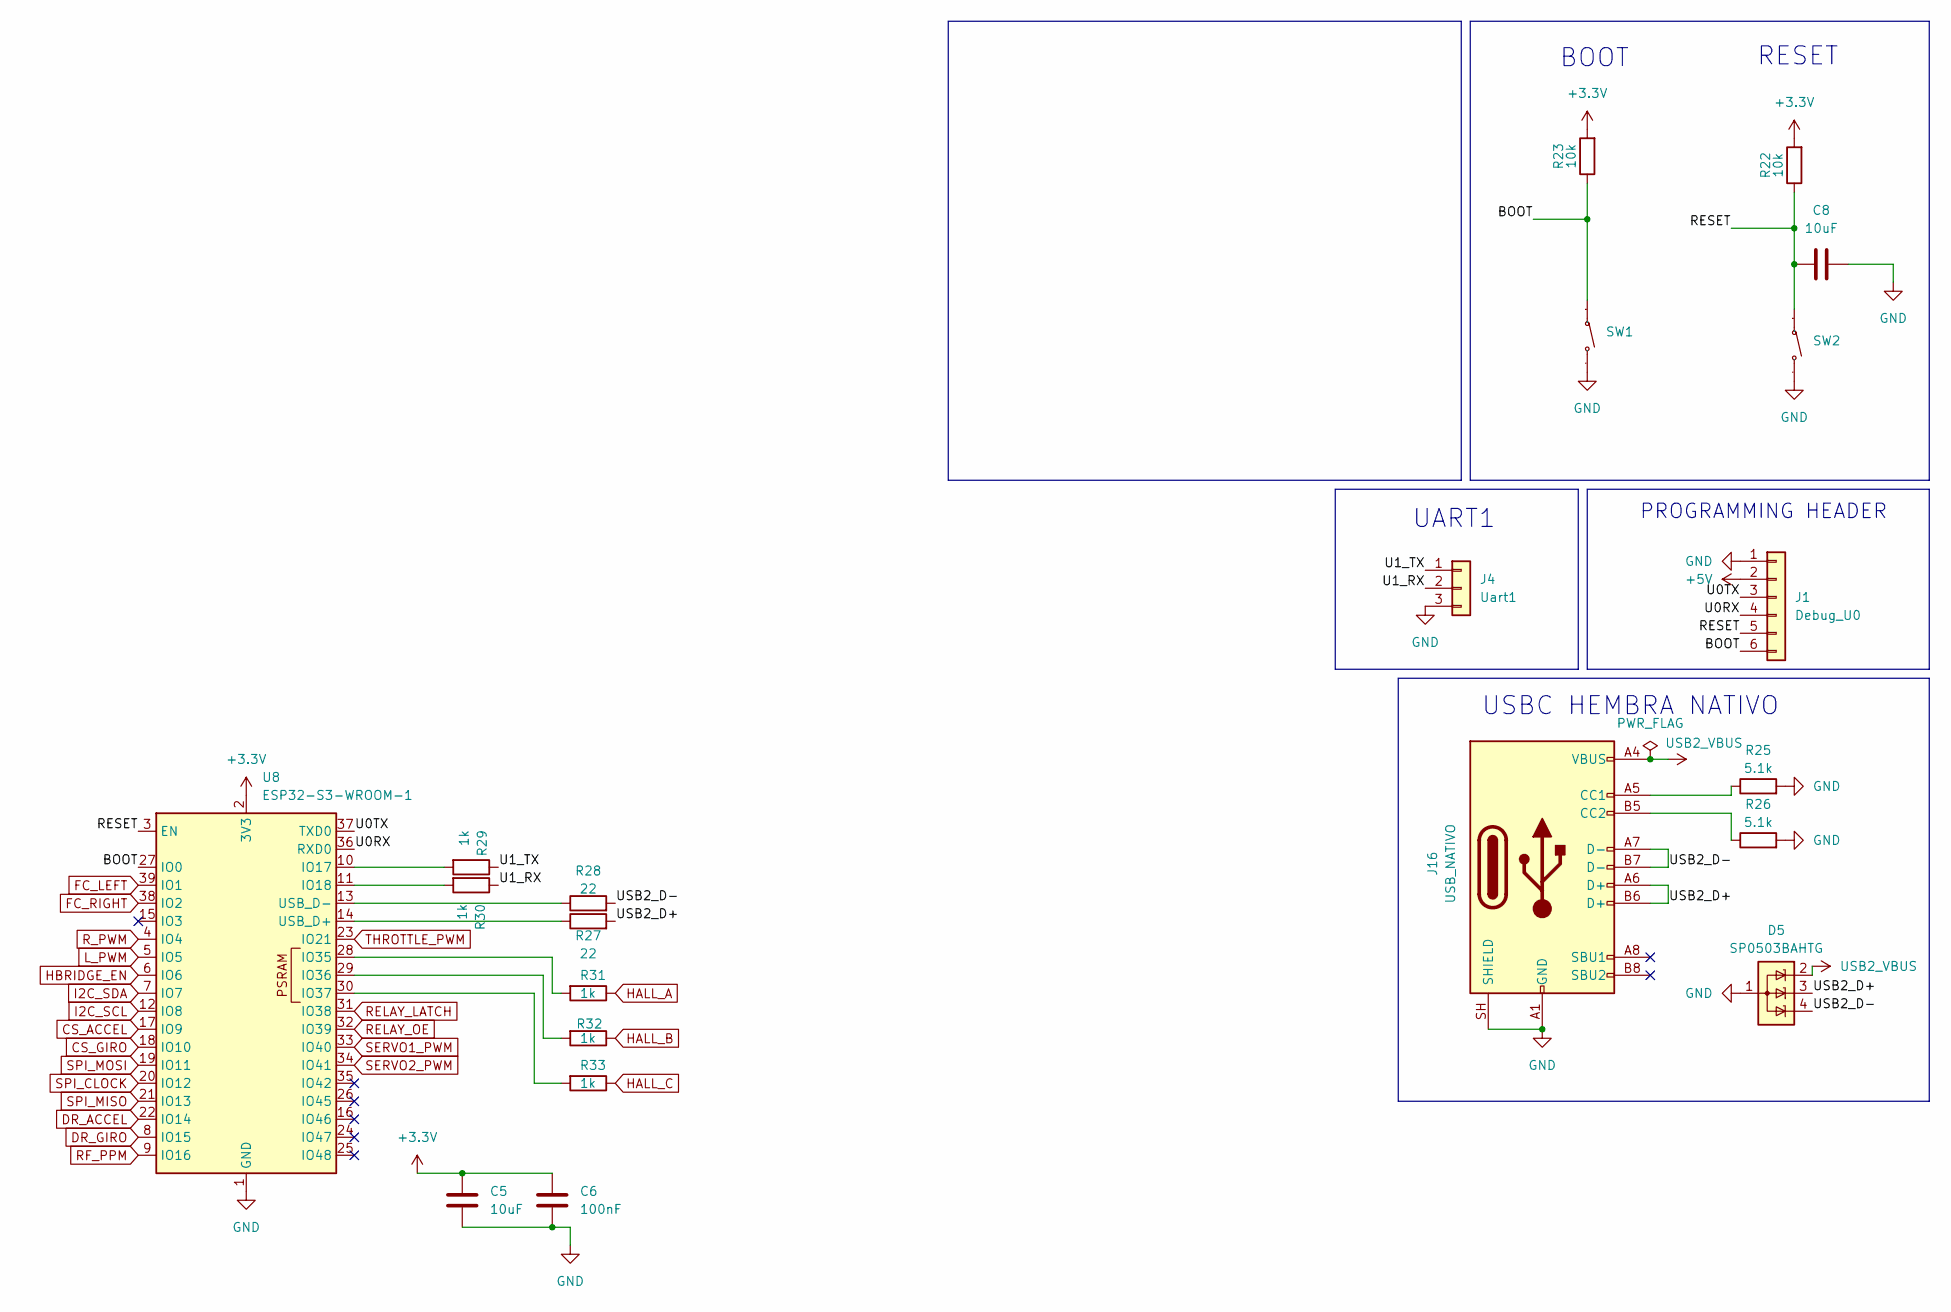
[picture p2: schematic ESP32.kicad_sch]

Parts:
C5, C8: 10uF; C_0805_2012Metric; Manufacturer Part CL21A106KPFNNNE; LCSC PN C17024
C6: 100nF; C_0603_1608Metric; Manufacturer Part CL10B104KA8NNNC; LCSC PN C1590
D5: SP0503BAHTG; SOT-143; Manufacturer Part SP0503BAHTG; LCSC PN C3040626
J1: Debug_U0; PinHeader_1x06_P2.54mm_Vertical; Manufacturer Part Header generico THT 1x06, P2.54 mm, ver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
J4: Uart1; PinHeader_1x03_P2.54mm_Vertical; Manufacturer Part Header generico THT 1x03, P2.54 mm, ver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
J16: USB_NATIVO; USB_C_Receptacle_G-Switch_GT-USB-7010ASV; Manufacturer Part GT-USB-7010ASV; LCSC PN C2988369
R22, R23: 10k; R_0603_1608Metric; Manufacturer Part 0603WAF1002T5E; LCSC PN C25804
R25, R26: 5.1k; R_0603_1608Metric; Manufacturer Part 0603WAF5101T5E; LCSC PN C23186
R27, R28: 22; R_0603_1608Metric; MPN 0603WAF220JT5E; LCSC PN C23345
R29, R30, R31, R32, R33: 1k; R_0603_1608Metric; Manufacturer Part 0603WAF1001T5E; LCSC PN C21190
SW1, SW2: Switch-Definitivo; Manufacturer Part TS-1187A-B-A-B; LCSC Part Name 立贴 轻触开关
U8: ESP32-S3-WROOM-1; Manufacturer Part ESP32-S3-WROOM-1-N8R2; LCSC PN C2913204

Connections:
+3.3V: C5.1, C6.1, R22.2, R23.2, U8.2 (3V3); also elsewhere on the board
+5V: J1.2; also elsewhere on the board
/ESP32/BOOT: J1.6, R23.1, SW1.1, U8.27 (IO0)
/ESP32/RESET: C8.1, J1.5, R22.1, SW2.1, U8.3 (EN)
/ESP32/U0RX: J1.4, U8.36 (RXD0)
/ESP32/U0TX: J1.3, U8.37 (TXD0)
/ESP32/U1_RX: J4.2, R30.1
/ESP32/U1_TX: J4.1, R29.1
/ESP32/USB2_D+: D5.3 (K), J16.A6 (D+), J16.B6 (D+), R27.2
/ESP32/USB2_D-: D5.4 (K), J16.A7 (D-), J16.B7 (D-), R28.2
CS_ACCEL: U8.17 (IO9); also elsewhere on the board
CS_GIRO: U8.18 (IO10); also elsewhere on the board
DR_ACCEL: U8.22 (IO14); also elsewhere on the board
DR_GIRO: U8.8 (IO15); also elsewhere on the board
FC_LEFT: U8.39 (IO1); also elsewhere on the board
FC_RIGHT: U8.38 (IO2); also elsewhere on the board
GND: C5.2, C6.2, C8.2, D5.1 (A), J1.1, J4.3, J16.A1 (GND), J16.A12 (GND), J16.B1 (GND), J16.B12 (GND), J16.SH (SHIELD), R25.2, R26.2, SW1.2, SW2.2, U8.1 (GND), U8.40 (GND), U8.41 (GND); also elsewhere on the board
HALL_A: R31.1; also elsewhere on the board
HALL_B: R32.1; also elsewhere on the board
HALL_C: R33.1; also elsewhere on the board
HBRIDGE_EN: U8.6 (IO6); also elsewhere on the board
I2C_SCL: U8.12 (IO8); also elsewhere on the board
I2C_SDA: U8.7 (IO7); also elsewhere on the board
L_PWM: U8.5 (IO5); also elsewhere on the board
unnamed: J16.A5 (CC1), R25.1
unnamed: J16.B5 (CC2), R26.1
unnamed: R29.2, U8.10 (IO17)
unnamed: R30.2, U8.11 (IO18)
unnamed: R31.2, U8.28 (IO35)
unnamed: R32.2, U8.29 (IO36)
unnamed: R33.2, U8.30 (IO37)
unnamed: R27.1, U8.14 (USB_D+)
unnamed: R28.1, U8.13 (USB_D-)
RELAY_LATCH: U8.31 (IO38); also elsewhere on the board
RELAY_OE: U8.32 (IO39); also elsewhere on the board
R_PWM: U8.4 (IO4); also elsewhere on the board
SERVO1_PWM: U8.33 (IO40); also elsewhere on the board
SERVO2_PWM: U8.34 (IO41); also elsewhere on the board
SPI_CLOCK: U8.20 (IO12); also elsewhere on the board
SPI_MISO: U8.21 (IO13); also elsewhere on the board
SPI_MOSI: U8.19 (IO11); also elsewhere on the board
THROTTLE_PWM: U8.23 (IO21); also elsewhere on the board
USB2_VBUS: D5.2 (K), J16.A4 (VBUS), J16.A9 (VBUS), J16.B4 (VBUS), J16.B9 (VBUS); also elsewhere on the board

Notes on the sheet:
BOOT
UART1
USBC HEMBRA NATIVO
RESET
PROGRAMMING HEADER

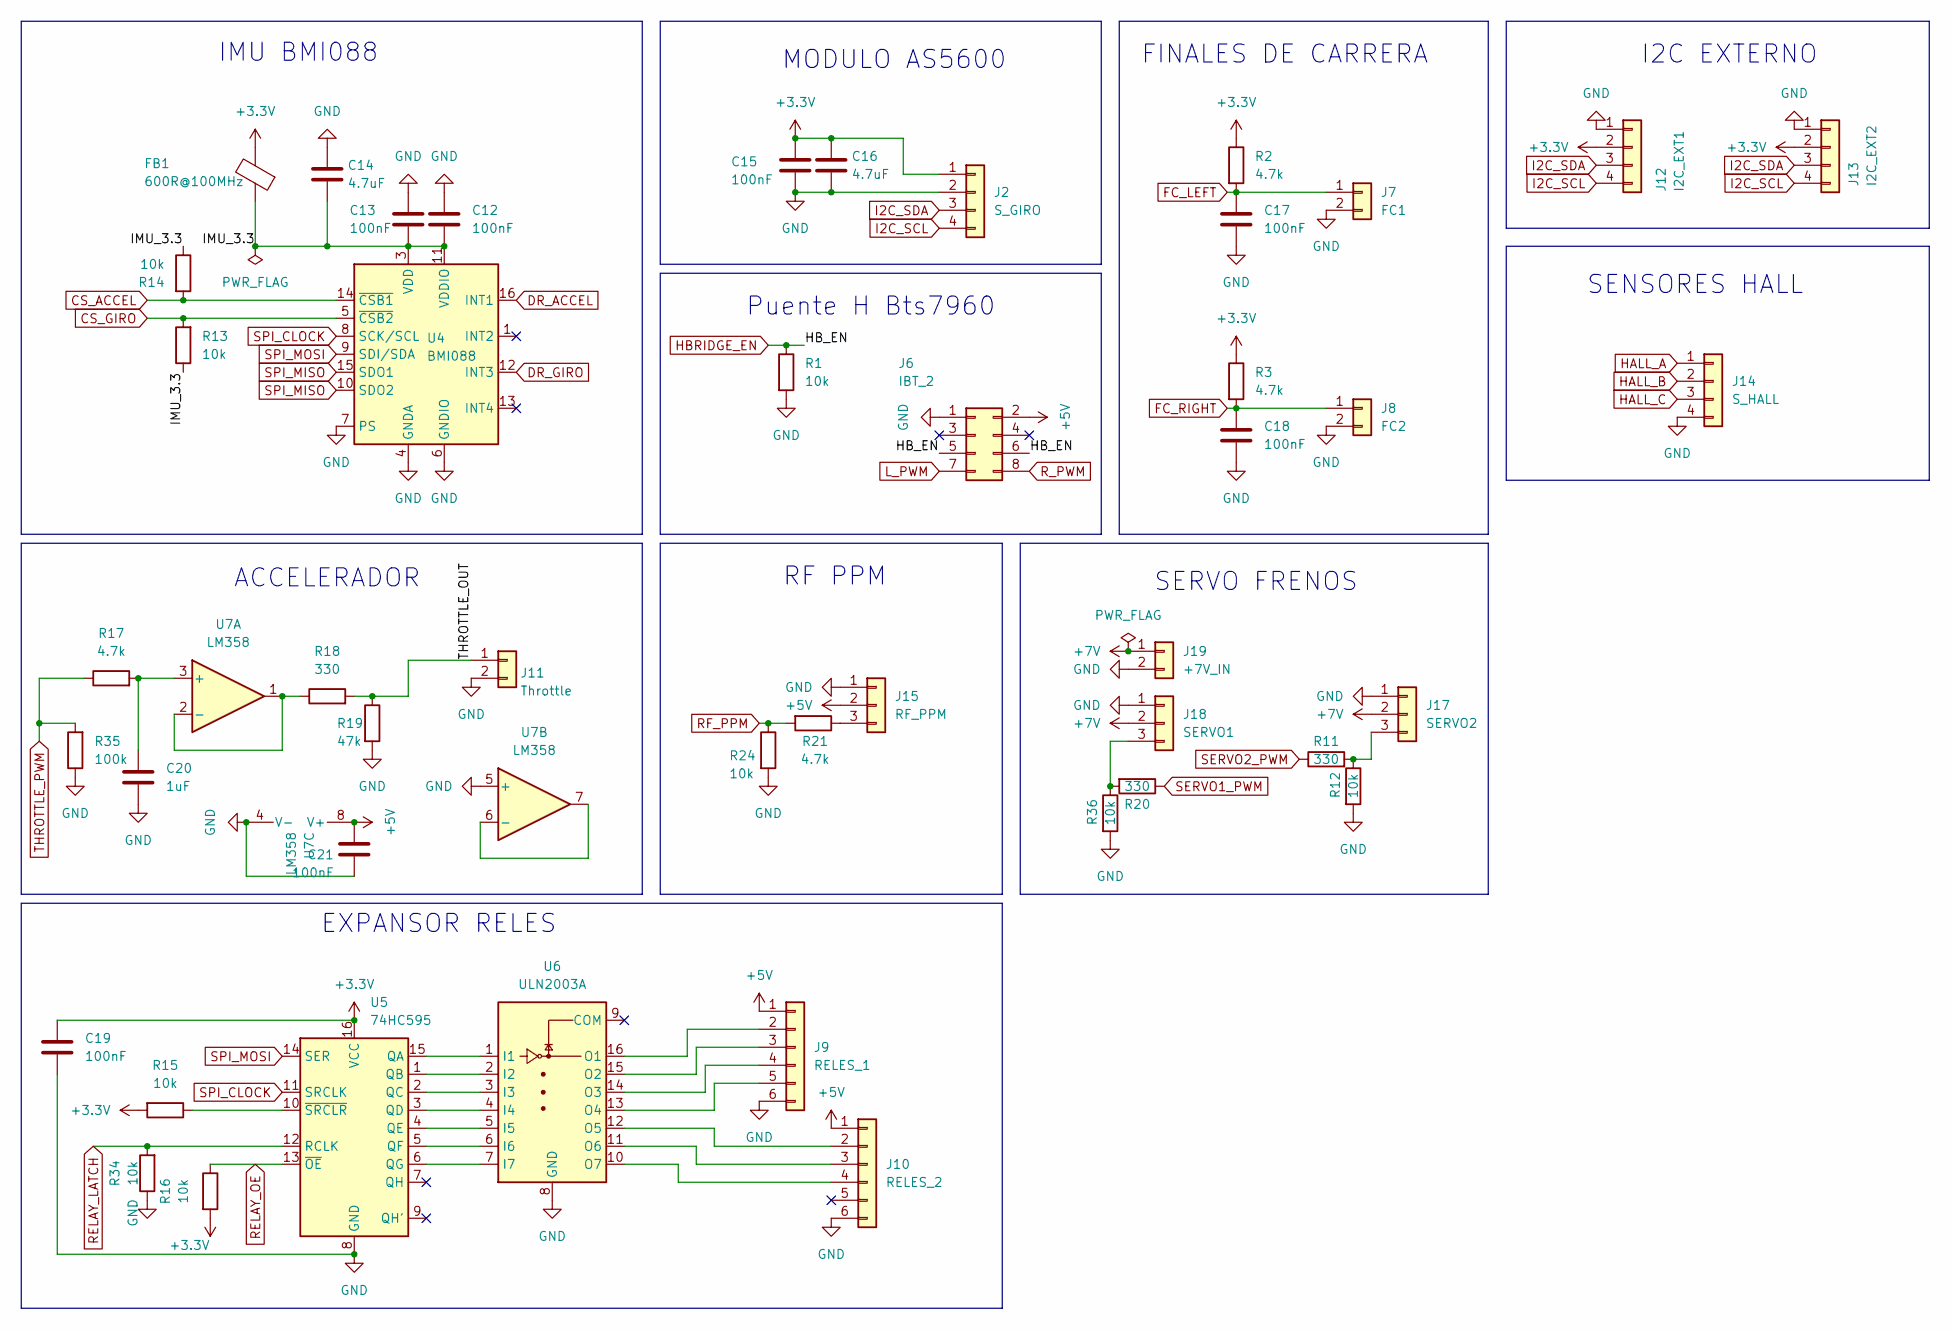
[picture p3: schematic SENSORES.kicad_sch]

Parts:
C12, C13, C15: 100nF; C_0603_1608Metric; Manufacturer Part CL10B104KA8NNNC; LCSC PN C1590
C14, C16: 4.7uF; C_0805_2012Metric; Manufacturer Part CC0805KKX5R6BB475; LCSC PN C107125
C17, C18, C19, C21: 100nF; C_0603_1608Metric; MPN CL10B104KA8NNNC; LCSC PN C1590
C20: 1uF; C_0603_1608Metric; MPN 0603B105K160CT; LCSC PN C108463
FB1: 600R@100MHz; L_0603_1608Metric_Pad1.05x0.95mm_HandSolder; Manufacturer Part GZ1608D601TF; LCSC PN C1002
J2: S_GIRO; PinHeader_1x04_P2.54mm_Vertical; MPN Header manual THT 1x04 P2.54 mm
J6: IBT_2; PinHeader_2x04_P2.54mm_Vertical; MPN Header manual THT 2x04 P2.54 mm
J7: FC1; PinHeader_1x02_P2.54mm_Vertical; MPN Header manual THT 1x02 P2.54 mm
J8: FC2; PinHeader_1x02_P2.54mm_Vertical; MPN Header manual THT 1x02 P2.54 mm
J9: RELES_1; PinHeader_1x06_P2.54mm_Vertical; MPN Header manual THT 1x06 P2.54 mm
J10: RELES_2; PinHeader_1x06_P2.54mm_Vertical; MPN Header manual THT 1x06 P2.54 mm
J11: Throttle; PinHeader_1x02_P2.54mm_Vertical; MPN Header manual THT 1x02 P2.54 mm
J12: I2C_EXT1; PinHeader_1x04_P2.54mm_Vertical; MPN Header manual THT 1x04 P2.54 mm
J13: I2C_EXT2; PinHeader_1x04_P2.54mm_Vertical; MPN Header manual THT 1x04 P2.54 mm
J14: S_HALL; PinHeader_1x04_P2.54mm_Vertical; MPN Header manual THT 1x04 P2.54 mm
J15: RF_PPM; PinHeader_1x03_P2.54mm_Vertical; MPN Header manual THT 1x03 P2.54 mm
J17: SERVO2; PinHeader_1x03_P2.54mm_Vertical; MPN Header manual THT 1x03 P2.54 mm
J18: SERVO1; PinHeader_1x03_P2.54mm_Vertical; MPN Header manual THT 1x03 P2.54 mm
J19: +7V_IN; PinHeader_1x02_P2.54mm_Vertical; MPN Header manual THT 1x02 P2.54 mm
R1, R12, R15, R16, R24, R34, R36: 10k; R_0603_1608Metric; MPN 0603WAF1002T5E; LCSC PN C25804
R2, R3, R17, R21: 4.7k; R_0603_1608Metric; MPN 0603WAF4701T5E; LCSC PN C23162
R11, R18, R20: 330; R_0603_1608Metric; MPN 0603WAF3300T5E; LCSC PN C23138
R13, R14: 10k; R_0603_1608Metric; Manufacturer Part 0603WAF1002T5E; LCSC PN C25804
R19: 47k; R_0603_1608Metric; MPN 0603WAF4702T5E; LCSC PN C25819
R35: 100k; R_0603_1608Metric; MPN 0603WAF1003T5E; LCSC PN C25803
U4: BMI088; Bosch_LGA-16_4.5x3mm_P0.5mm_LayoutBorder7x1y_ClockwisePinNu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; Manufacturer Part BMI088; LCSC PN C194919
U5: 74HC595; SOIC-16_3.9x9.9mm_P1.27mm; Manufacturer Part SN74HC595DR; LCSC PN C10092
U6: ULN2003A; SOIC-16_3.9x9.9mm_P1.27mm; Manufacturer Part ULN2003BDR; LCSC PN C157485
U7: LM358; SOIC-8_3.9x4.9mm_P1.27mm; Manufacturer Part LM358DR; LCSC PN C5423

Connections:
+3.3V: C15.2, C16.1, C19.1, FB1.2, J2.1, J12.2, J13.2, R2.1, R3.1, R15.2, R16.2, U5.16 (VCC); also elsewhere on the board
+5V: C21.1, J6.2, J9.1, J10.1, J15.2, U7.8 (V+); also elsewhere on the board
+7V: J17.2, J18.2, J19.1
/SENSORES/IMU_3.3: C12.2, C13.1, C14.2, FB1.1, R13.1, R14.1, U4.3 (VDD), U4.11 (VDDIO)
/SENSORES/THROTTLE_OUT: J11.1, R18.2, R19.1
CS_ACCEL: R14.2, U4.14 (~CSB1); also elsewhere on the board
CS_GIRO: R13.2, U4.5 (~CSB2); also elsewhere on the board
DR_ACCEL: U4.16 (INT1); also elsewhere on the board
DR_GIRO: U4.12 (INT3); also elsewhere on the board
FC_LEFT: C17.1, J7.1, R2.2; also elsewhere on the board
FC_RIGHT: C18.1, J8.1, R3.2; also elsewhere on the board
GND: C12.1, C13.2, C14.1, C15.1, C16.2, C17.2, C18.2, C19.2, C20.2, C21.2, J2.2, J6.1, J7.2, J8.2, J9.6, J10.6, J11.2, J12.1, J13.1, J14.4, J15.1, J17.1, J18.1, J19.2, R1.2, R12.2, R19.2, R24.2, R34.1, R35.1, R36.2, U4.2 (GNDA), U4.4 (GNDA), U4.6 (GNDIO), U4.7 (PS), U5.8 (GND), U6.8 (GND), U7.4 (V-), U7.5 (+); also elsewhere on the board
HALL_A: J14.1; also elsewhere on the board
HALL_B: J14.2; also elsewhere on the board
HALL_C: J14.3; also elsewhere on the board
HBRIDGE_EN: J6.5, J6.6, R1.1; also elsewhere on the board
I2C_SCL: J2.4, J12.4, J13.4; also elsewhere on the board
I2C_SDA: J2.3, J12.3, J13.3; also elsewhere on the board
L_PWM: J6.7; also elsewhere on the board
unnamed: J9.2, U6.16 (O1)
unnamed: J9.3, U6.15 (O2)
unnamed: J9.4, U6.14 (O3)
unnamed: J9.5, U6.13 (O4)
unnamed: J10.2, U6.12 (O5)
unnamed: J10.3, U6.11 (O6)
unnamed: J10.4, U6.10 (O7)
unnamed: J17.3, R11.2, R12.1
unnamed: J18.3, R20.2, R36.1
unnamed: U5.15 (QA), U6.1 (I1)
unnamed: U5.1 (QB), U6.2 (I2)
unnamed: U5.2 (QC), U6.3 (I3)
unnamed: U5.3 (QD), U6.4 (I4)
unnamed: U5.4 (QE), U6.5 (I5)
unnamed: U5.5 (QF), U6.6 (I6)
unnamed: U5.6 (QG), U6.7 (I7)
unnamed: R15.1, U5.10 (~SRCLR)
unnamed: C20.1, R17.2, U7.3 (+)
unnamed: R18.1, U7.1, U7.2 (-)
unnamed: U7.6 (-), U7.7
RELAY_LATCH: R34.2, U5.12 (RCLK); also elsewhere on the board
RELAY_OE: R16.1, U5.13 (~OE); also elsewhere on the board
R_PWM: J6.8; also elsewhere on the board
SERVO1_PWM: R20.1; also elsewhere on the board
SERVO2_PWM: R11.1; also elsewhere on the board
SPI_CLOCK: U4.8 (SCK/SCL), U5.11 (SRCLK); also elsewhere on the board
SPI_MISO: U4.10 (SDO2), U4.15 (SDO1); also elsewhere on the board
SPI_MOSI: U4.9 (SDI/SDA), U5.14 (SER); also elsewhere on the board
THROTTLE_PWM: R17.1, R35.2; also elsewhere on the board

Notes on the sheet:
MODULO AS5600
Puente H Bts7960
EXPANSOR RELES
FINALES DE CARRERA
ACCELERADOR
SENSORES HALL
RF PPM
IMU BMI088
I2C EXTERNO
SERVO FRENOS

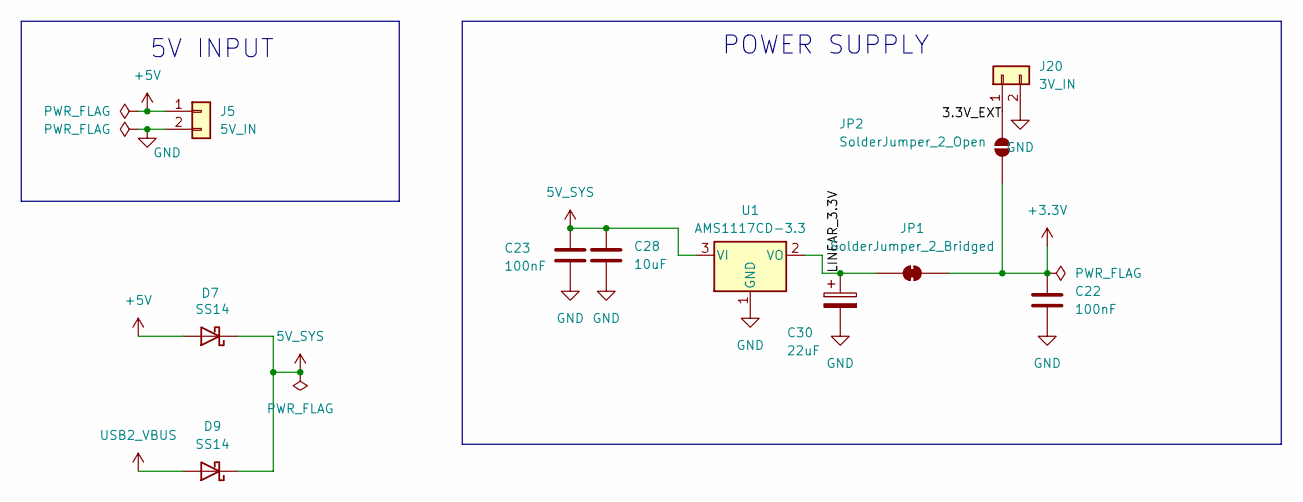
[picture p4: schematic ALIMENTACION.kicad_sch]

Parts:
C22, C23: 100nF; C_0603_1608Metric; Manufacturer Part CL10B104KA8NNNC; LCSC PN C1590
C28: 10uF; C_0805_2012Metric; Manufacturer Part CL21A106KPFNNNE; LCSC PN C17024
C30: 22uF; CP_EIA-3528-21_Kemet-B; Manufacturer Part T491B226K010AT; LCSC PN C117030
D7, D9: SS14; D_SMA; Manufacturer Part SS14; LCSC PN C2480
J5: 5V_IN; PinHeader_1x02_P2.54mm_Vertical; MPN Header manual THT 1x02 P2.54 mm
J20: 3V_IN; PinHeader_1x02_P2.54mm_Vertical
JP1: SolderJumper_2_Bridged; SolderJumper-2_P1.3mm_Bridged_RoundedPad1.0x1.5mm
JP2: SolderJumper_2_Open; SolderJumper-2_P1.3mm_Open_RoundedPad1.0x1.5mm
U1: AMS1117CD-3.3; TO-252-3_TabPin2; MPN AMS1117CD-3.3; LCSC PN C841796

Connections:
5V_SYS: C23.1, C28.1, D7.1 (K), D9.1 (K), U1.3 (VI)
+3.3V: C22.1, JP1.2 (B), JP2.2 (B); also elsewhere on the board
+5V: D7.2 (A), J5.1; also elsewhere on the board
/ALIMENTACION/LINEAR_3.3V: C30.1, JP1.1 (A), U1.2 (VO)
GND: C22.2, C23.2, C28.2, C30.2, J5.2, J20.2, U1.1 (GND); also elsewhere on the board
unnamed: J20.1, JP2.1 (A)
USB2_VBUS: D9.2 (A); also elsewhere on the board

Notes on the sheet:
POWER SUPPLY
5V INPUT

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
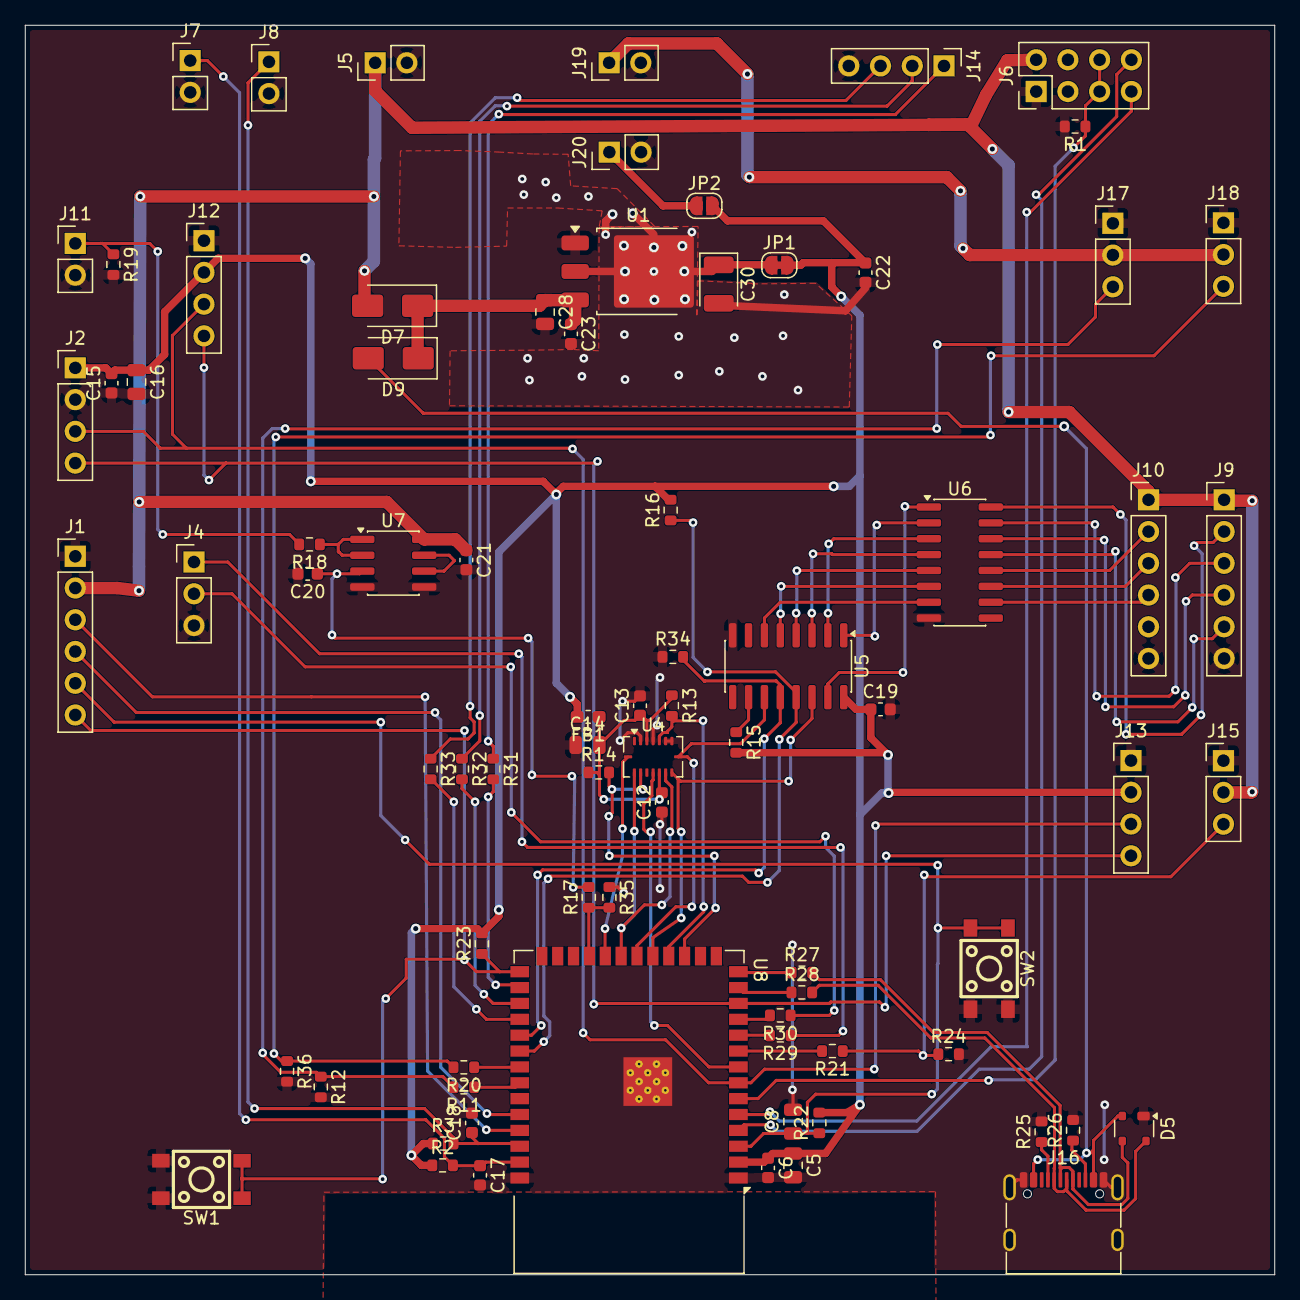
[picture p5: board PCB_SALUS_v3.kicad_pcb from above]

Board: 2 copper layers, 100.0 x 100.0 mm, 79 parts (0 on the bottom side), 71 nets.

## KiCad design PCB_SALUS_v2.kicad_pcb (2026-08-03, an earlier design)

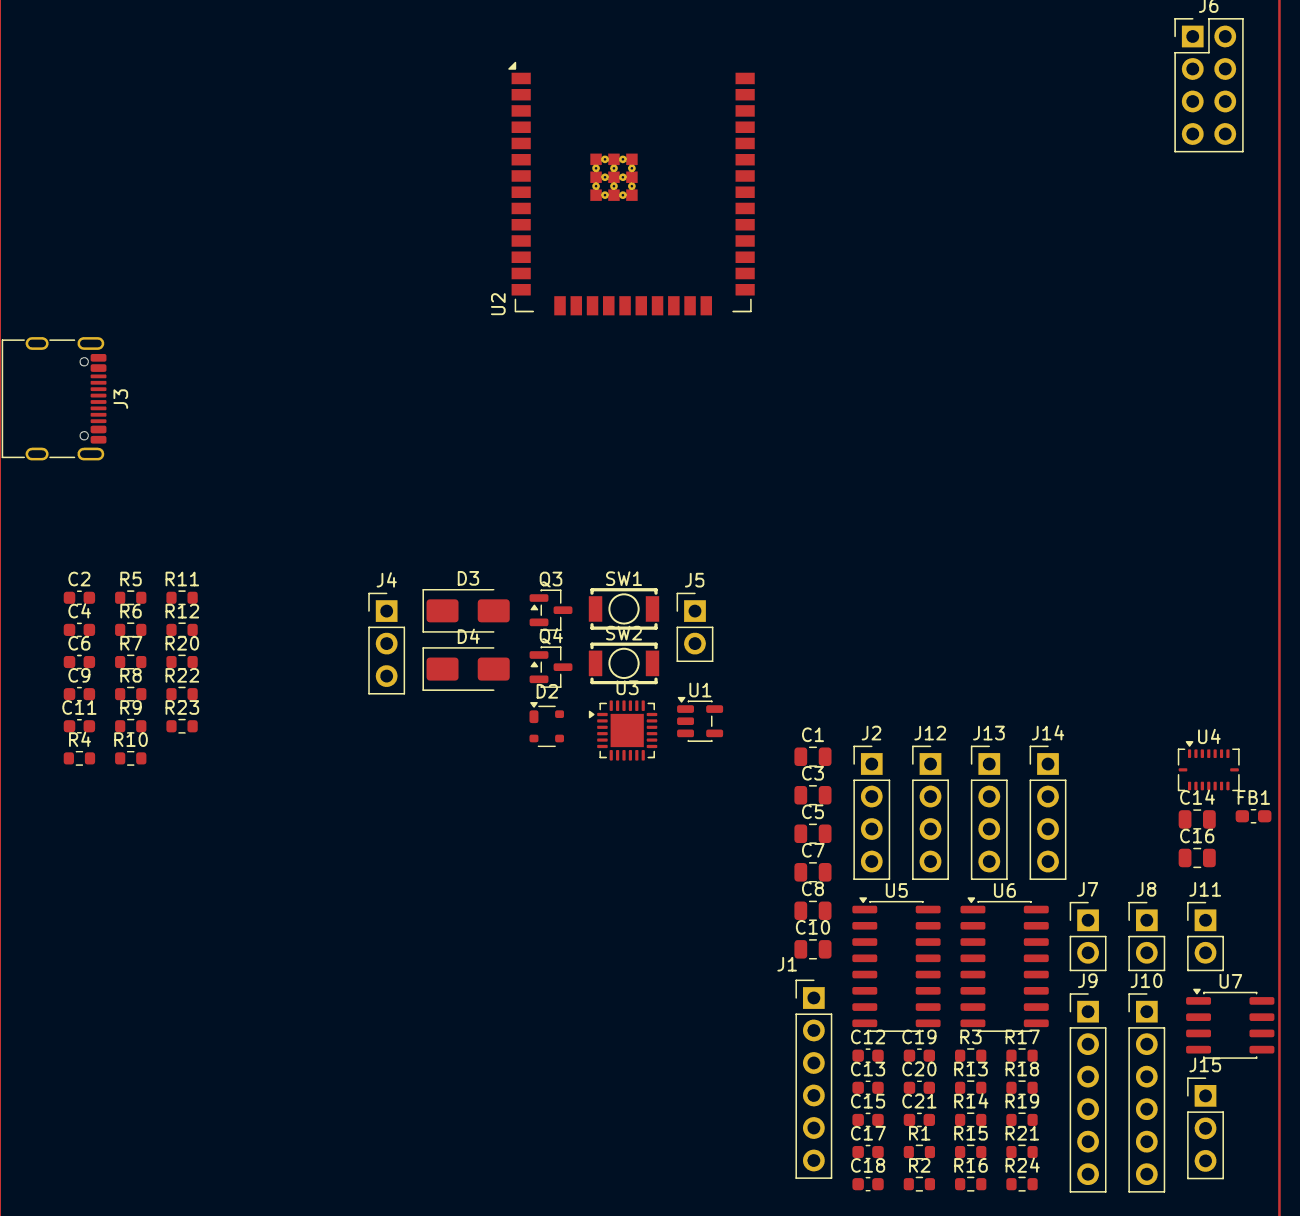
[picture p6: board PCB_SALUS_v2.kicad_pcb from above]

Board: 2 copper layers, 75 parts (0 on the bottom side), 65 nets, no tracks yet.

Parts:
C1, C3, C5, C8: 10uF; C_0805_2012Metric
C2, C4, C6, C9, C11, C12, C13, C15, C17, C18, C19, C20, C21: 100nF; C_0603_1608Metric
C7, C10, C14, C16: 4.7uF; C_0805_2012Metric
D2: SP0503BAHTG; SOT-143
D3, D4: SS14; D_SMA
FB1: 600R@100MHz; L_0603_1608Metric_Pad1.05x0.95mm_HandSolder
J1: Header_THT_1x06_P2.54mm; PinHeader_1x06_P2.54mm_Vertical
J2, J12, J13, J14: Conn_01x04; PinHeader_1x04_P2.54mm_Vertical
J3: USB_C_Receptacle_USB2.0_16P; USB_C_Receptacle_G-Switch_GT-USB-7010ASV
J4: Header_THT_1x03_P2.54mm; PinHeader_1x03_P2.54mm_Vertical
J5, J7, J8, J11: Conn_01x02; PinHeader_1x02_P2.54mm_Vertical
J6: Conn_02x04_Odd_Even; PinHeader_2x04_P2.54mm_Vertical
J9, J10: Conn_01x06; PinHeader_1x06_P2.54mm_Vertical
J15: Conn_01x03; PinHeader_1x03_P2.54mm_Vertical
Q3, Q4: SS8050; SOT-23
R1, R8, R9, R13, R14, R15, R16, R20, R22, R23, R24: 10k; R_0603_1608Metric
R2, R3: R; R_0603_1608Metric
R4, R5: 5.1k; R_0603_1608Metric
R6: 22.1k; R_0603_1608Metric
R7: 47.5k; R_0603_1608Metric
R10, R11, R12, R17: 1k; R_0603_1608Metric
R18: 330; R_0603_1608Metric
R19: 47k; R_0603_1608Metric
R21: 4.7k; R_0603_1608Metric
SW1, SW2: Boton_Simple
U1: TLV75733PDBV; SOT-23-5
U2: ESP32-WROOM-32E
U3: CP2102N-A02-GQFN24; QFN-24-1EP_4x4mm_P0.5mm_EP2.6x2.6mm
U4: BMI088; Bosch_LGA-16_4.5x3mm_P0.5mm_LayoutBorder7x1y_ClockwisePinNu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
U5: 74HC595; SOIC-16_3.9x9.9mm_P1.27mm
U6: ULN2003A; SOIC-16_3.9x9.9mm_P1.27mm
U7: LM358; SOIC-8_3.9x4.9mm_P1.27mm

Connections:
5V_SYS: C3.1, C4.1, D3.1 (K), D4.1 (K), U1.1 (IN), U1.3 (EN)
+3.3V: C1.1, C2.1, C5.1, C6.1, C15.2, C16.1, C19.1, FB1.2, J2.1, J12.2, J13.2, R2.1, R3.1, R15.2, R16.2, R22.2, R23.2, U1.5 (OUT), U2.2 (VDD), U5.16 (VCC)
+5V: C21.1, D3.2 (A), J1.2, J5.1, J6.2, J9.1, J10.1, J15.2, U7.8 (V+)
/ESP32/BOOT: J1.6, Q4.3 (C), R23.1, SW1.1, U2.25 (IO0)
/ESP32/DTR: Q4.2 (E), R8.1, U3.23 (~DTR)
/ESP32/RESET: C8.1, J1.5, Q3.3 (C), R22.1, SW2.1, U2.3 (EN)
/ESP32/RTS: Q3.2 (E), R9.1, U3.19 (~RTS)
/ESP32/U0RX: J1.4, U2.34 (RXD0/IO3), U3.21 (TXD)
/ESP32/U0TX: J1.3, U2.35 (TXD0/IO1), U3.20 (RXD)
/ESP32/U1_RX: J4.2, R11.1
/ESP32/U1_TX: J4.1, R12.1
/ESP32/USB_DM: D2.4 (K), J3.A7 (D-), J3.B7 (D-), U3.4 (D-)
/ESP32/USB_DP: D2.3 (K), J3.A6 (D+), J3.B6 (D+), U3.3 (D+)
/SENSORES/IMU_3.3: C12.2, C13.1, C14.2, FB1.1, R13.1, R14.1, U4.3 (VDD), U4.11 (VDDIO)
/SENSORES/THROTTLE_OUT: J11.1, R18.2, R19.1
CP2102_3V3: C10.2, C11.1, R10.1, U3.5 (VIO), U3.6 (VDD)
CS_ACCEL: R14.2, U2.26 (IO4), U4.14 (~CSB1)
CS_GIRO: R13.2, U2.11 (IO26), U4.5 (~CSB2)
DAC: R17.1, U2.10 (IO25)
DR_ACCEL: U2.6 (IO34), U4.16 (INT1)
DR_GIRO: U2.7 (IO35), U4.12 (INT3)
FC_LEFT: C17.1, J7.1, R2.2, U2.4 (SENSOR_VP)
FC_RIGHT: C18.1, J8.1, R3.2, U2.5 (SENSOR_VN)
GND: C1.2, C2.2, C3.2, C4.2, C5.2, C6.2, C7.1, C8.2, C9.2, C10.1, C11.2, C12.1, C13.2, C14.1, C15.1, C16.2, C17.2, C18.2, C19.2, C20.2, C21.2, D2.1 (A), J1.1, J2.2, J3.A1 (GND), J3.A12 (GND), J3.B1 (GND), J3.B12 (GND), J3.SH (SHIELD), J4.3, J5.2, J6.1, J7.2, J8.2, J9.6, J10.6, J11.2, J12.1, J13.1, J14.4, J15.1, R1.2, R4.2, R5.2, R7.2, R19.2, R20.1, R24.2, SW1.2, SW2.2, U1.2 (GND), U2.1 (GND), U2.15 (GND), U2.38 (GND), U2.39 (GND), U3.2 (GND), U3.25 (GND), U4.2 (GNDA), U4.4 (GNDA), U4.6 (GNDIO), U4.7 (PS), U5.8 (GND), U6.8 (GND), U7.4 (V-), U7.5 (+)
HALL_A: J14.1, U2.29 (IO5)
HALL_B: J14.2, U2.16 (IO13)
HALL_C: J14.3, U2.23 (IO15)
HBRIDGE_EN: J6.5, J6.6, R1.1, U5.6 (QG)
I2C_SCL: J2.4, J12.4, J13.4, U2.36 (IO22)
I2C_SDA: J2.3, J12.3, J13.3, U2.33 (IO21)
L_PWM: J6.7, U2.9 (IO33)
unnamed: J3.A5 (CC1), R4.1
unnamed: J3.B5 (CC2), R5.1
unnamed: J9.2, U6.16 (O1)
unnamed: J9.3, U6.15 (O2)
unnamed: J9.4, U6.14 (O3)
unnamed: J9.5, U6.13 (O4)
unnamed: J10.2, U6.12 (O5)
unnamed: J10.3, U6.11 (O6)
unnamed: J10.4, U6.10 (O7)
unnamed: J15.3, R21.1, R24.1
unnamed: Q3.1 (B), R8.2
unnamed: Q4.1 (B), R9.2
unnamed: R11.2, U2.27 (IO16)
unnamed: R12.2, U2.28 (IO17)
unnamed: R6.2, R7.1, U3.8 (VBUS)
unnamed: R10.2, U3.9 (~RST)
unnamed: U5.15 (QA), U6.1 (I1)
unnamed: U5.1 (QB), U6.2 (I2)
unnamed: U5.2 (QC), U6.3 (I3)
unnamed: U5.3 (QD), U6.4 (I4)
unnamed: U5.4 (QE), U6.5 (I5)
unnamed: U5.5 (QF), U6.6 (I6)
unnamed: R15.1, U5.10 (~SRCLR)
unnamed: C20.1, R17.2, U7.3 (+)
unnamed: R18.1, U7.1, U7.2 (-)
unnamed: U7.6 (-), U7.7
RELAY_LATCH: R20.2, U2.14 (IO12), U5.12 (RCLK)
RELAY_OE: R16.1, U2.13 (IO14), U5.13 (~OE)
RF_PPM: R21.2, U2.8 (IO32)
R_PWM: J6.8, U2.12 (IO27)
SPI_CLOCK: U2.30 (IO18), U4.8 (SCK/SCL), U5.11 (SRCLK)
SPI_MISO: U2.31 (IO19), U4.10 (SDO2), U4.15 (SDO1)
SPI_MOSI: U2.37 (IO23), U4.9 (SDI/SDA), U5.14 (SER)
USB_VBUS: C7.2, C9.1, D2.2 (K), D4.2 (A), J3.A4 (VBUS), J3.A9 (VBUS), J3.B4 (VBUS), J3.B9 (VBUS), R6.1, U3.7 (VREGIN)

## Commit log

2026-07-17 Initial PCB SALUS V3 project
    [ALIMENTACION.kicad_sch, ESP32.kicad_sch, PCB_SALUS_v3.kicad_pcb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]
2026-07-30 routeo terminado v1
    [PCB_SALUS_v3.kicad_pcb, SENSORES.kicad_sch]
2026-07-31 buck remplazado por regulador lineal
    [ALIMENTACION.kicad_sch, PCB_SALUS_v3.kicad_pcb, SENSORES.kicad_sch]
2026-07-31 removed usb_uart0
    [ALIMENTACION.kicad_sch, ESP32.kicad_sch, PCB_SALUS_v3.kicad_pcb]
2026-07-31 se hicieron los boom, cpl y gerbers
    [ALIMENTACION.kicad_sch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]
2026-08-03 RS485 upgrades
    [ESP32.kicad_sch, PCB_SALUS_v3.kicad_pcb]
2026-08-07 add second header for rs485
    [ESP32.kicad_sch, PCB_SALUS_v3.kicad_pcb]
2026-08-12 vias de gnd y pin header de GPIOS sobrantes
    [ESP32.kicad_sch, PCB_SALUS_v3.kicad_pcb]
2026-08-12 coreccion de value j22
    [ESP32.kicad_sch]
2026-08-12 Mejora serigrafia profesional SALUS v3
    [PCB_SALUS_v3.kicad_pcb]
2026-08-12 Identifica pines criticos de conectores
    [PCB_SALUS_v3.kicad_pcb]
2026-08-12 Libera paquete JLCPCB SALUS v3
    [ALIMENTACION.kicad_sch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]
2026-08-12 Ajusta rotaciones CPL para JLCPCB
    [rotaciones_criticas.csv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]
2026-08-12 Agrega generador CPL auditable para JLCPCB
2026-08-13 Calibra CPL final para JLCPCB
    [PCB_SALUS_v3-JLC-CPL-candidate.csv, PCB_SALUS_v3-JLC-CPL-raw.csv, cpl-candidate-review.csv]
2026-08-13 Consolida pasivos Basic y valida filtro de acelerador
    [ALIMENTACION.kicad_sch, ESP32.kicad_sch, PCB_SALUS_v3-JLC-BOM.csv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]
2026-10-15 Registra PCB SALUS v3 con montaje M3 y terminacion RS485
    Conserva los dos paquetes de fabricacion del 20 de agosto, sus fuentes, checksums y validaciones. El paquete final monta R4 de 120 ohm e incluye 64 componentes SMD. Actualiza el README para identific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
2026-10-15 Organiza entregas de fabricacion y archivo historico
    Separa entrega actual, historicos y cotizaciones. Conserva archivos originales, actualiza rutas de pruebas y documentacion, y hace portables los manifiestos SHA-256.
2026-10-15 Documenta revision de PCB y decisiones de alimentacion y USB
2026-10-15 docs: record BMI088 hardware synchronization for next PCB revision
